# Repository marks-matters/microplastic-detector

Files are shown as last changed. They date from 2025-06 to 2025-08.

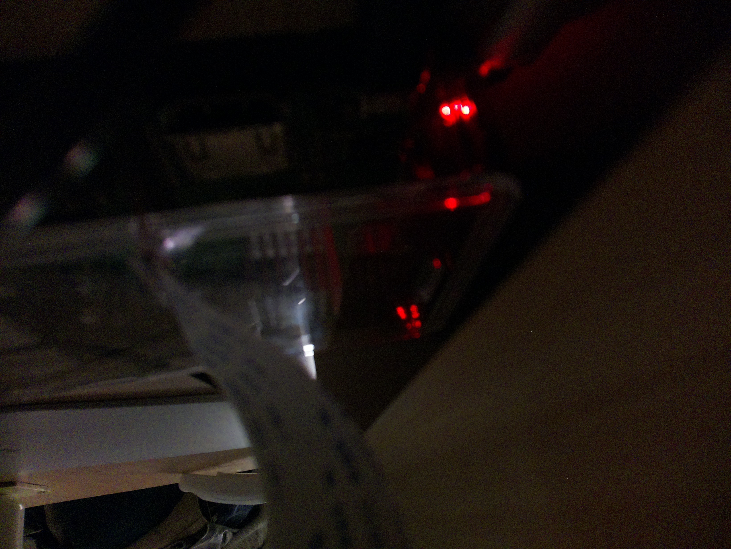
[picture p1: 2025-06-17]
tests/test-images/sample_20250616_235741.jpg

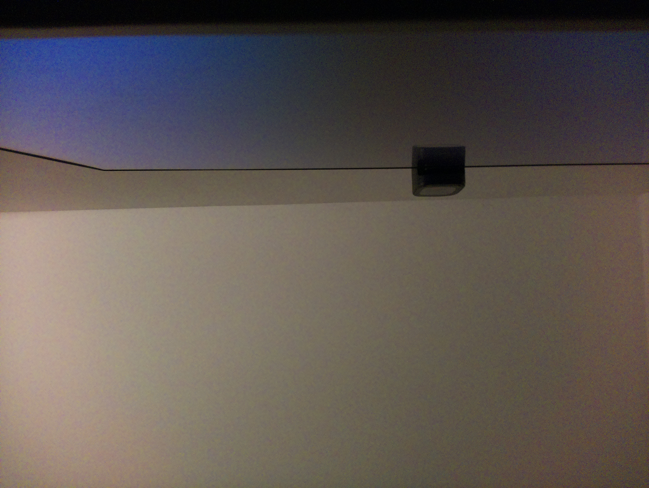
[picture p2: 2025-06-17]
tests/test-images/sample_20250616_233426.jpg

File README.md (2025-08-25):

# Microplastic Detector

A Python-based tool for analyzing fluorescence images to detect and categorize microplastic particles. This tool uses computer vision techniques to identify, count, and classify microplastic particles in fluorescence microscopy images.

## Features

- Automated detection of microplastic particles in fluorescence images
- Particle counting and size filtering
- Classification into Low/Medium/High concentration categories
- Visual output with multiple analysis stages
- Comprehensive test suite for reliability

## Prerequisites

- Python 3.13 or higher
- Virtual environment (included in repository)
- OpenCV
- NumPy
- Matplotlib
- pytest (for running tests)
- gpiozero

## Setup Instructions

1. Clone the repository:
   ```bash
   git clone <repository-url>
   cd microplastic-detector
   ```

2. Activate the virtual environment:
   ```bash
   source microplastics-env/bin/activate
   ```

3. Install required packages:
   ```bash
   pip install opencv-python numpy matplotlib pytest
   ```

### Setup Instructions for Raspberry Pi

0. Setup Raspberry Pi and install the camera:
   ```bash
   sudo ssh admin@microplastics-ui.local
   sudo raspi-config
   ```

   Go to:

   >   Interface Options → Camera → Enable

   Reboot:
   ```bash
   sudo reboot
   ```

1. Update `apt` and install dependencies `venv` and `opencv`:
   ```bash
   sudo apt update
   sudo apt install python3-venv python3-opencv -y
   ```

2. Set up project file and environment:
   ```bash
   cd ~
   mkdir mp-proj
   cd ~/mp-proj
   python3 -m venv --system-site-packages ~/mp-proj/mp-env
   python3 -m venv mp-env
   ```

3. Transfer files to the Raspberry Pi:
   ```bash
   sudo scp -r software admin@microplastics-ui.local:~/mp-proj/
   ```

4. Activate the virtual environment and install the required packages:
   ```bash
   cd ~/mp-proj
   source mp-env/bin/activate
   pip install -r software/requirements.txt
   ```

5. Run the python script
   ```bash
   python -m software.main
   ```

## Usage

To analyze a single image:

```bash
python -m software.analyze_microplastics --image_path image_name.jpg --show_image_processing
```

```python
from software.analyze_microplastics import analyze_microplastics

# Basic usage
count, category = analyze_microplastics("path/to/your/image.jpg")

# Advanced usage with all parameters
count, category = analyze_microplastics(
    image_path="path/to/your/image.jpg",
    min_area=10,                 # Minimum particle size in pixels
    max_area=5000,               # Maximum particle size in pixels
    low_thresh=10,               # Threshold for "Low" category
    high_thresh=30,              # Threshold for "Medium" category
    show_image_processing=False  # Whether to display visualization
)

print(f"Detected particles: {count}")
print(f"Concentration category: {category}")
```

### Parameters

- `image_path`: Path to the fluorescence image
- `min_area`: Minimum particle area to count (default: 10 pixels)
- `max_area`: Maximum particle area to count (default: 5000 pixels)
- `low_thresh`: Maximum particle count for "Low" classification (default: 10)
- `high_thresh`: Maximum particle count for "Medium" classification (default: 30)
- `show_image_processing`: Whether to display visualization plots (default: False)

### Return Values

Returns a tuple containing:
1. `count` (int): Number of detected particles
2. `category` (str): Concentration category ("Low", "Medium", or "High")

## Testing

The project includes comprehensive test suites for all components. To run the tests:

1. Ensure you're in the virtual environment:
   ```bash
   source microplastics-env/bin/activate
   ```

2. Run all tests:
   ```bash
   pytest tests/ -v
   ```

3. Run specific test files:
   ```bash
   pytest tests/test_analyze_microplastics.py -v  # Analysis tests
   pytest tests/test_capture_image.py -v          # Image capture tests
   pytest tests/test_main.py -v                   # Main pipeline tests
   ```

Additional test options:
- Use `-v` for verbose output
- Run specific tests: `pytest tests/test_capture_image.py -k "failure"`
- Show print statements: `pytest tests/ -s`

## Test Coverage

The test suite covers:

### Analysis Module
- Basic functionality and return types
- Threshold handling
- Area filtering
- Edge cases (zero/negative values)
- Input validation
- File handling
- Result consistency

### Image Capture Module
- Directory creation
- File naming conventions
- Error handling
- Hardware failure scenarios

### Main Pipeline
- Integration tests
- End-to-end workflow
- Error propagation

## Useful functions

To copy a file from the Raspberry Pi back to your local machine, use:

/home/admin/mp-proj/captures
```bash
sudo scp admin@microplastics-ui.local:/home/admin/mp-proj/captures/sample_20250801_225616.jpg ./captures/
```

## Contributing

1. Create a fork
2. Create your feature branch
3. Make your changes
4. Run the test suite to ensure everything works
5. Update documentation if needed (see Documentation section below)
6. Submit a pull request

## Documentation

This project includes automated documentation update triggers. When making changes to core functionality, please ensure documentation stays current:

### Files that may need updates:
- **README.md**: User-facing documentation, API examples, setup instructions
- **.github/instructions/microplastic-detector.instructions.md**: AI agent guidance and contracts
- **.cursor/rules/**: Documentation standards and automated update triggers

### Common update triggers:
- Function signature changes → Update README examples and AI contracts
- New dependencies → Update setup instructions
- New features → Document usage examples and workflows
- Directory structure changes → Update file listings and references
- Test structure changes → Update testing documentation

The repository includes automated rules in `.cursor/rules/` that will suggest documentation updates when relevant changes are detected. These rules include:

- **File organization standards**: Naming conventions and structure guidelines
- **Documentation triggers**: Broad change detection for documentation updates
- **README consistency**: Specific checks for README accuracy
- **AI instructions consistency**: Maintains AI guidance accuracy
- **Meta-update rules**: Self-referential updates for documentation standards

## License

This project is licensed under the MIT License - see the [LICENSE](LICENSE) file for details.

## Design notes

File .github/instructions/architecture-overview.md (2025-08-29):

---
description: High-level architecture and workflow overview for the microplastic detector
applyTo: "**"
---

# Architecture Overview

Purpose: Understand the big picture architecture and core workflow of the microplastic detector system.

## System Architecture

The microplastic detector consists of two main components:

### 1. Hardware-Enabled Python Pipeline (`software/`)
- **Purpose**: Complete capture → analysis → report workflow
- **Platform**: Raspberry Pi with camera and LED hardware
- **Components**:
  - Image capture using `libcamera-still`
  - LED illumination control via GPIO
  - OpenCV-based microplastic analysis
  - Result reporting and storage

### 2. Optional React Frontend (`app/`)
- **Purpose**: Standalone UI for visualization and interaction
- **Platform**: Web-based (Vite + React + TypeScript)
- **Status**: Not currently wired to Python backend
- **Use Case**: Development, demonstration, future web interface

## Core Workflow

The main pipeline (`software/main.py`) follows this sequence:

```
1. illuminate_sample(lights=True)     # Turn on LEDs (GPIO 23/24/27)
2. capture_image()                    # Run libcamera-still → captures/sample_YYYYMMDD_HHMMSS.jpg
3. analyze_microplastics(path)        # OpenCV HSV masks + morphology → count + risk level
4. finally: illuminate_sample(lights=False) + cleanup()  # Always turn off LEDs
```

### Analysis Pipeline Details

The `analyze_microplastics()` function implements:
1. **Color Space Conversion**: BGR → HSV
2. **Color Filtering**: Masks for deep_red, red, orange, yellow
3. **Image Processing**: Gaussian blur → bilateral filter → Otsu thresholding
4. **Morphological Operations**: Opening with 3×3 ellipse kernel
5. **Contour Detection**: Find and count particles
6. **Classification**: Count → Low/Medium/High risk categories

## Data Flow

```
Hardware Input → Image Capture → Analysis → Results
     ↓              ↓             ↓         ↓
LED + Camera → .jpg files → OpenCV → Count + Risk Level
```

## File Organization

- **`software/`**: Core Python modules
- **`captures/`**: Timestamped sample images
- **`tests/`**: Unit tests and test images
- **`app/`**: React frontend (standalone)
- **`hardware/`**: 3D models and hardware specs

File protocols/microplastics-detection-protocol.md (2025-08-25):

# Microplastics Detection Protocol

## Materials
- **Tap water sample**, 20 mL
- **Syringe**, ≤10 mL capacity
- **Pipette**, ≥10 mL capacity
- **Filter holder** with funnel and vacuum-enabled catchment beaker
- **Nylon membrane filter**, 47 mm diameter, 0.22 µm pore size
- **Vacuum pump**, 5v
- **Absolute ethanol**, ≥96%
- **Nile Red powder**
- **2 x amber vials** for stock and working solutions
- **Micropipette** for 100 µL dispensing
- **Raspberry Pi Camera 2** with lense manually turned to desired focal distance
- **6 mm macro lens**
- **LEE Lee No. 105 Orange (~560 nm) long-pass emission filter**
- **LED ring with camera window and leg threads**, the 10 x LED slots angled inwards at 45° and 5 x leg threads
- **10 x green LED lights** with a wavelength of 485–545 nm (peak at 515 nm) and a viewing angle of 50°
- **5 x 60 mm legs** with screw thread
- **Light shield** to block out light during florencence and imaging
- **N-MOSFET**, logic-level
- **Resistors**, 11 x 220 Ω (one per LED and one for the MOSFET gate) and 1 x 10 kΩ as a gate pull-down
- **5 V regulated supply** via Raspberry Pi 5 V rail
- **Petri dishes**, 60 mm, for positioning membrane, and 50 mm for covering during staining
- **Raspberry Pi** with image capture and analysis software
- **Breadboard** for wiring up LEDs, MOSFET and vacuum
- **Connector cables**

---

## 1. Nile Red Working Solution Preparation
- **Stock solution**: 1 mg/mL Nile Red in absolute ethanol (96%).  
- **Working solution**: dilute 0.1 mL stock + 0.9 mL ethanol to get **100 µg/mL**.  
- Prepare working solution fresh before staining.

---

## 2. Sample Measurement
- Measure **20 mL** of tap water using a clean syringe or pipette.  
- No pretreatment (e.g., oxidation or digestion) is applied.

---

## 3. Filtration
- Place a **47 mm nylon membrane filter, with 0.22 µm pore size** into the filter holder.  
- Pass the **20 mL sample** through the membrane using **gentle vacuum**.  
- Allow the membrane to **partially air dry** under gentle vacuum.

---

## 4. Staining the Membrane
- Transfer the membrane to a **60 mm Petri dish**.
- **Apply 4-5 drops**, totalling ~100 µL, of the 100 µg/mL Nile Red working solution evenly over the surface.
- Incubate for **30 minutes**, partially covered with another Petri dish and protected from light.
<!-- - Apply gentle vacuum for **1 minute** to remove excess solution. -->

---

## 5. Imaging Setup
- Use a **Raspberry Pi Camera 2** with an attached **6 mm lens** at **60 mm distance** from the membrane.
- **Emission filter** (Orange) placed behind the lens.
- **10 green LEDs** (515 nm) mounted in parallel, with 220 Ω resistors, at ~45° around membrane.
- LEDs powered from 5 V rail, switched by N-MOSFET from Pi GPIO.
- LEDs on during capture; camera uses long exposure.

---

## 6. Image Capture & Processing
- Capture image via Pi software.
- Processing pipeline:
  1. Convert to HSV color space.
  2. Mask relevant hue ranges (deep red/red/orange).
  3. Blur, threshold, and clean image.
  4. Detect contours and count particles.
  5. Classify count into **Low / Medium / High**.

---

## 7. Cleanup
- Turn off LEDs via software.
- Remove or store membrane as needed.
- Save image and analysis output.

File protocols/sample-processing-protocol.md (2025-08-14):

# Microplastics Detection Protocol

## 1. Sample Measurement
- Measure **10 mL** of tap water using a clean syringe or pipette.  
- No pretreatment (e.g., oxidation or digestion) is applied.

---

## 2. Filtration
- Place a **47 mm nylon membrane filter** (0.22 µm pore size) into the filter holder.  
- Pass the **10 mL sample** through the membrane using gentle vacuum.  
- Allow the membrane to **air dry under gentle vacuum** until mostly dry.

---

## 3. Nile Red Working Solution Preparation
- **Stock solution**: 1 mg/mL Nile Red in absolute ethanol (96%).  
- **Working solution**: dilute 0.1 mL stock + 0.9 mL ethanol to get **100 µg/mL**.  
- Prepare working solution fresh before staining.

---

## 4. Staining the Membrane
- With the membrane still in the holder:
  - Apply ~100 µL of the **100 µg/mL Nile Red** working solution evenly over the surface.
  - Incubate for **2 minutes** protected from light.
  - Apply gentle vacuum for **1 minute** to remove excess solution.

---

## 5. Imaging Setup
- Keep membrane in place on holder or 60 mm Petri dish.
- Use **Raspberry Pi Camera 2** + **6 mm lens** at **60 mm distance** from membrane.
- **Emission filter** (golden amber) placed behind the lens.
- **10 green LEDs** (560–568 nm) mounted at ~45° around membrane.
- LEDs powered from 5 V rail, switched by N-MOSFET from Pi GPIO.
- LEDs on during capture; camera uses long exposure.

---

## 6. Image Capture & Processing
- Capture image via Pi software.
- Processing pipeline:
  1. Convert to HSV color space.
  2. Mask relevant hue ranges (red/orange/yellow/green).
  3. Blur, threshold, and clean image.
  4. Detect contours and count particles.
  5. Classify count into **Low / Medium / High**.

---

## 7. Cleanup
- Turn off LEDs via software.
- Remove or store membrane as needed.
- Save image and analysis output.

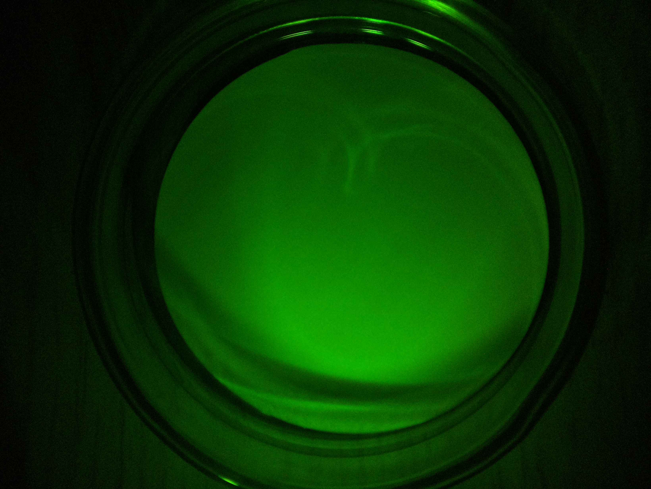
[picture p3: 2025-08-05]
captures/sample_20250801_225616.jpg

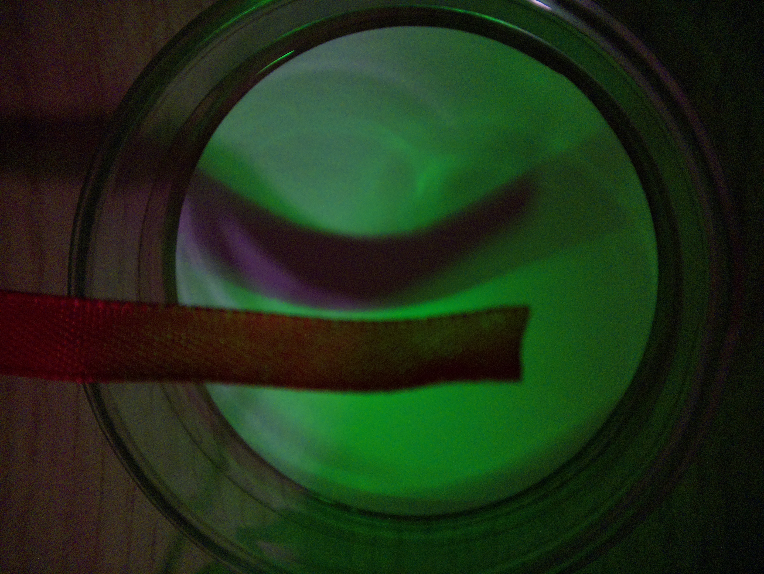
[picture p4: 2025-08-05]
captures/sample_20250801_232240.jpg

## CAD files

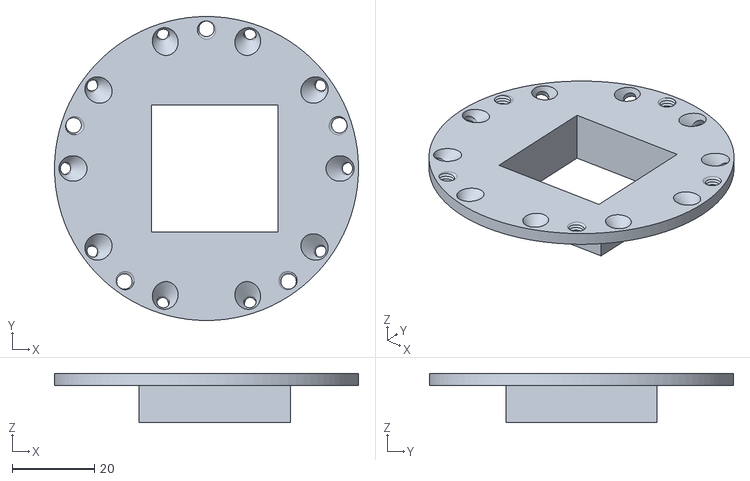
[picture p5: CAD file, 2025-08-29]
hardware/core_body_WP710A10ZGDK_10.stl
74.0 x 74.0 x 12.0

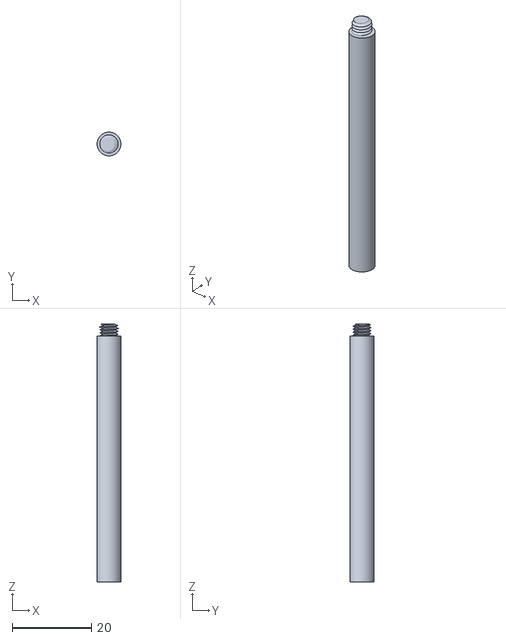
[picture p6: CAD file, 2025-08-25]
hardware/core_leg_62.stl
6.00 x 6.00 x 65.0

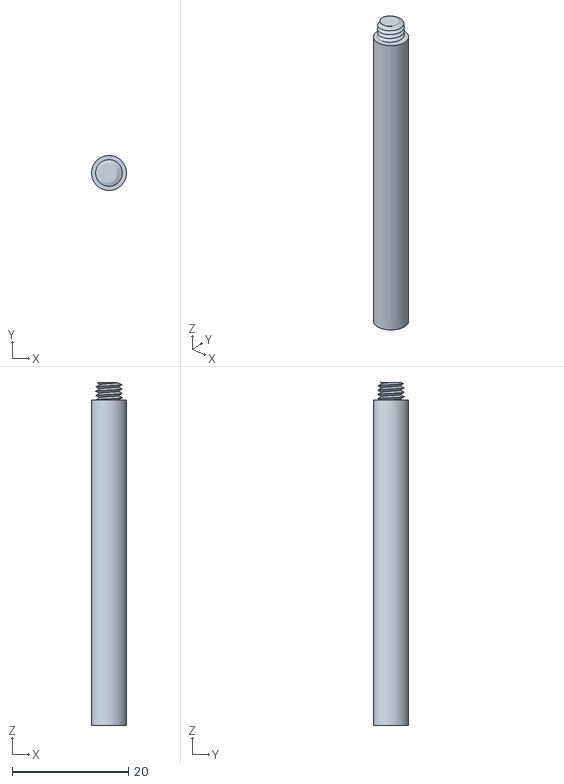
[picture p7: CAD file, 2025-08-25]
hardware/core_leg_56.stl
6.00 x 6.00 x 59.0

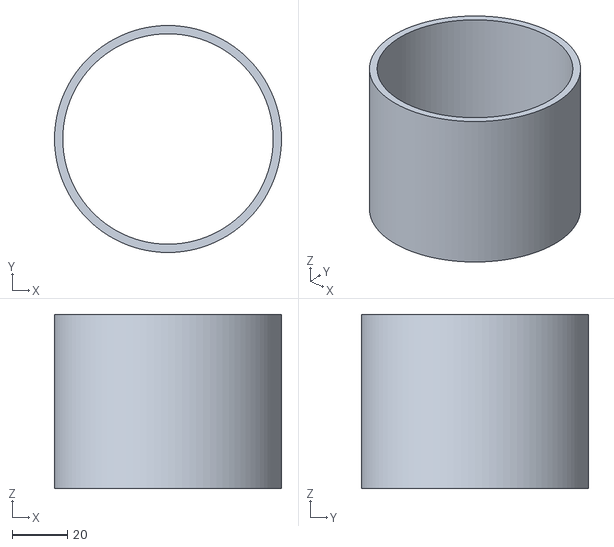
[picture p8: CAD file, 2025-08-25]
hardware/core_cover_v2.stl
82.0 x 82.0 x 63.0

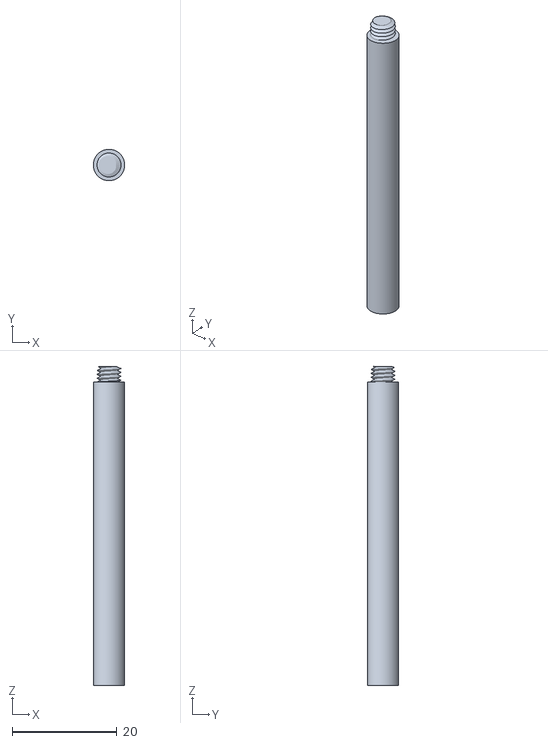
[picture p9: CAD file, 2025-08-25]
hardware/core_leg_58.stl
6.00 x 6.00 x 61.0

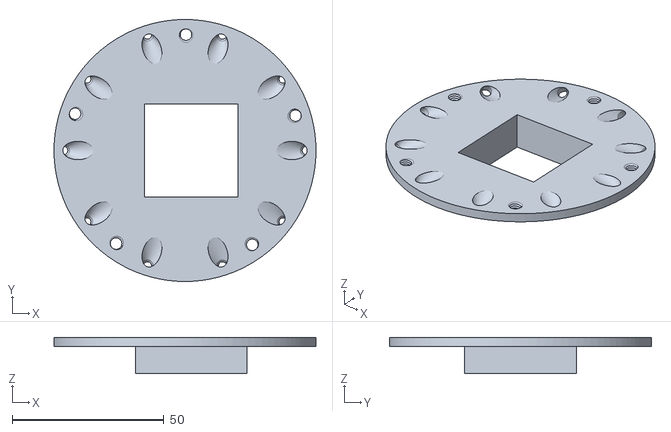
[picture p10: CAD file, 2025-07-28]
hardware/core_body.stl
86.4 x 86.4 x 12.0

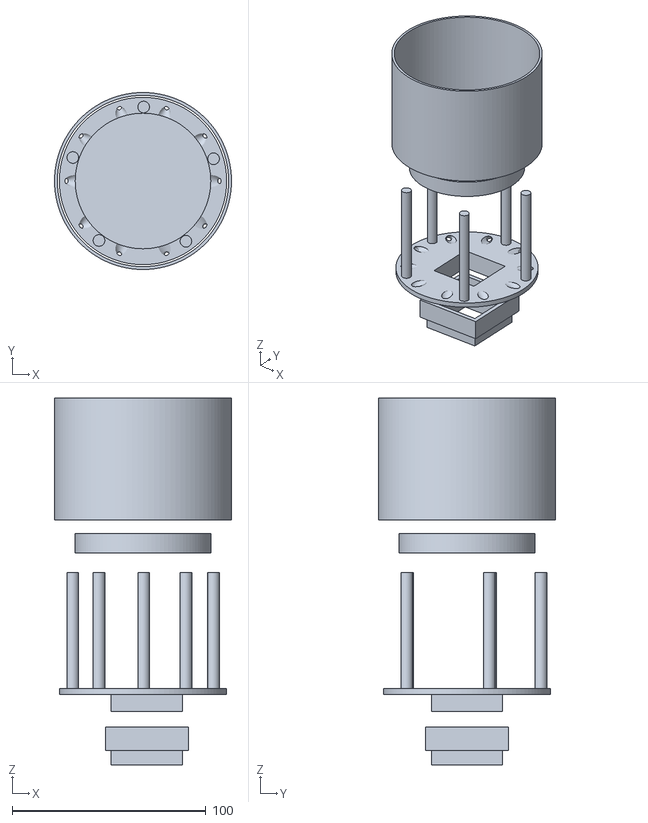
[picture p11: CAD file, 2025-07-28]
hardware/md_housing_v0.stl
91.4 x 91.4 x 189.5

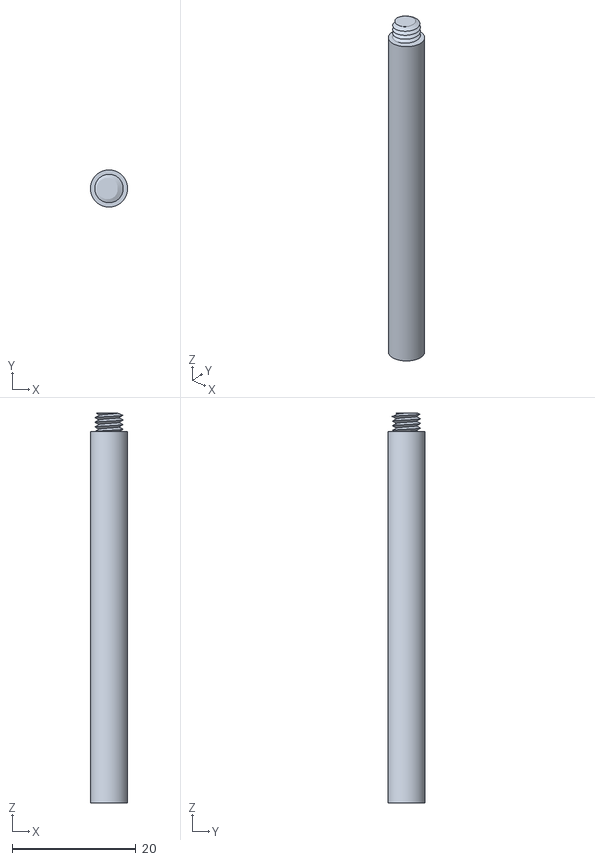
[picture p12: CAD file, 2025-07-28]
hardware/core_leg.stl
6.00 x 6.00 x 63.0

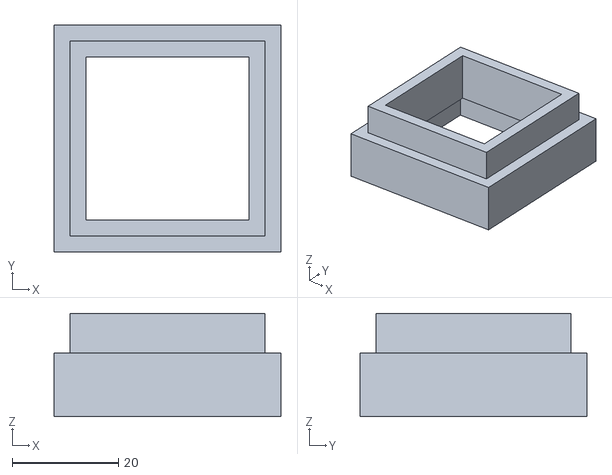
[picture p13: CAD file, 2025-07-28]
hardware/camera_extension.stl
42.8 x 42.8 x 19.5

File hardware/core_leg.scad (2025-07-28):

// Created 2016-2017 by Ryan A. Colyer.
// This work is released with CC0 into the public domain.
// https://creativecommons.org/publicdomain/zero/1.0/
//
// https://www.thingiverse.com/thing:1686322
//
// v2.1

$fn = 100;

screw_resolution = 0.5;  // in mm

// Legs
leg_diameter = 6;
leg_height = 60;

// Provides standard metric thread pitches.
function ThreadPitch(diameter) =
  (diameter <= 64) ?
    lookup(diameter, [
      [2, 0.4],
      [2.5, 0.45],
      [3, 0.5],
      [4, 0.7],
      [5, 0.8],
      [6, 1.0],
      [7, 1.0],
      [8, 1.25],
      [10, 1.5],
      [12, 1.75],
      [14, 2.0],
      [16, 2.0],
      [18, 2.5],
      [20, 2.5],
      [22, 2.5],
      [24, 3.0],
      [27, 3.0],
      [30, 3.5],
      [33, 3.5],
      [36, 4.0],
      [39, 4.0],
      [42, 4.5],
      [48, 5.0],
      [52, 5.0],
      [56, 5.5],
      [60, 5.5],
      [64, 6.0]
    ]) :
    diameter * 6.0 / 64;


// This generates a closed polyhedron from an array of arrays of points,
// with each inner array tracing out one loop outlining the polyhedron.
// pointarrays should contain an array of N arrays each of size P outlining a
// closed manifold.  The points must obey the right-hand rule.  For example,
// looking down, the P points in the inner arrays are counter-clockwise in a
// loop, while the N point arrays increase in height.  Points in each inner
// array do not need to be equal height, but they usually should not meet or
// cross the line segments from the adjacent points in the other arrays.
// (N>=2, P>=3)
// Core triangles:
//   [j][i], [j+1][i], [j+1][(i+1)%P]
//   [j][i], [j+1][(i+1)%P], [j][(i+1)%P]
//   Then triangles are formed in a loop with the middle point of the first
//   and last array.
module ClosePoints(pointarrays) {
  function recurse_avg(arr, n=0, p=[0,0,0]) = (n>=len(arr)) ? p :
    recurse_avg(arr, n+1, p+(arr[n]-p)/(n+1));

  N = len(pointarrays);
  P = len(pointarrays[0]);
  NP = N*P;
  lastarr = pointarrays[N-1];
  midbot = recurse_avg(pointarrays[0]);
  midtop = recurse_avg(pointarrays[N-1]);

  faces_bot = [
    for (i=[0:P-1])
      [0,i+1,1+(i+1)%len(pointarrays[0])]
  ];

  loop_offset = 1;
  bot_len = loop_offset + P;

  faces_loop = [
    for (j=[0:N-2], i=[0:P-1], t=[0:1])
      [loop_offset, loop_offset, loop_offset] + (t==0 ?
      [j*P+i, (j+1)*P+i, (j+1)*P+(i+1)%P] :
      [j*P+i, (j+1)*P+(i+1)%P, j*P+(i+1)%P])
  ];

  top_offset = loop_offset + NP - P;
  midtop_offset = top_offset + P;

  faces_top = [
    for (i=[0:P-1])
      [midtop_offset,top_offset+(i+1)%P,top_offset+i]
  ];

  points = [
    for (i=[-1:NP])
      (i<0) ? midbot :
      ((i==NP) ? midtop :
      pointarrays[floor(i/P)][i%P])
  ];
  faces = concat(faces_bot, faces_loop, faces_top);

  polyhedron(points=points, faces=faces);
}

// This creates a vertical rod at the origin with external threads.  It uses
// metric standards by default.
module ScrewThread(outer_diam, height, pitch=0, tooth_angle=30, tolerance=0.4, tip_height=0, tooth_height=0, tip_min_fract=0) {

  pitch = (pitch==0) ? ThreadPitch(outer_diam) : pitch;
  tooth_height = (tooth_height==0) ? pitch : tooth_height;
  tip_min_fract = (tip_min_fract<0) ? 0 :
    ((tip_min_fract>0.9999) ? 0.9999 : tip_min_fract);

  outer_diam_cor = outer_diam + 0.25*tolerance; // Plastic shrinkage correction
  inner_diam = outer_diam - tooth_height/tan(tooth_angle);
  or = (outer_diam_cor < screw_resolution) ?
    screw_resolution/2 : outer_diam_cor / 2;
  ir = (inner_diam < screw_resolution) ? screw_resolution/2 : inner_diam / 2;
  height = (height < screw_resolution) ? screw_resolution : height;

  steps_per_loop_try = ceil(2*3.14159265359*or / screw_resolution);
  steps_per_loop = (steps_per_loop_try < 4) ? 4 : steps_per_loop_try;
  hs_ext = 3;
  hsteps = ceil(3 * height / pitch) + 2*hs_ext;

  extent = or - ir;

  tip_start = height-tip_height;
  tip_height_sc = tip_height / (1-tip_min_fract);

  tip_height_ir = (tip_height_sc > tooth_height/2) ?
    tip_height_sc - tooth_height/2 : tip_height_sc;

  tip_height_w = (tip_height_sc > tooth_height) ? tooth_height : tip_height_sc;
  tip_wstart = height + tip_height_sc - tip_height - tip_height_w;


  function tooth_width(a, h, pitch, tooth_height, extent) =
    let(
      ang_full = h*360.0/pitch-a,
      ang_pn = atan2(sin(ang_full), cos(ang_full)),
      ang = ang_pn < 0 ? ang_pn+360 : ang_pn,
      frac = ang/360,
      tfrac_half = tooth_height / (2*pitch),
      tfrac_cut = 2*tfrac_half
    )
    (frac > tfrac_cut) ? 0 : (
      (frac <= tfrac_half) ?
        ((frac / tfrac_half) * extent) :
        ((1 - (frac - tfrac_half)/tfrac_half) * extent)
    );


  pointarrays = [
    for (hs=[0:hsteps])
      [
        for (s=[0:steps_per_loop-1])
          let(
            ang_full = s*360.0/steps_per_loop,
            ang_pn = atan2(sin(ang_full), cos(ang_full)),
            ang = ang_pn < 0 ? ang_pn+360 : ang_pn,

            h_fudge = pitch*0.001,

            h_mod =
              (hs%3 == 2) ?
                ((s == steps_per_loop-1) ? tooth_height - h_fudge : (
                 (s == steps_per_loop-2) ? tooth_height/2 : 0)) : (
              (hs%3 == 0) ?
                ((s == steps_per_loop-1) ? pitch-tooth_height/2 : (
                 (s == steps_per_loop-2) ? pitch-tooth_height + h_fudge : 0)) :
                ((s == steps_per_loop-1) ? pitch-tooth_height/2 + h_fudge : (
                 (s == steps_per_loop-2) ? tooth_height/2 : 0))
              ),

            h_level =
              (hs%3 == 2) ? tooth_height - h_fudge : (
              (hs%3 == 0) ? 0 : tooth_height/2),

            h_ub = floor((hs-hs_ext)/3) * pitch
              + h_level + ang*pitch/360.0 - h_mod,
            h_max = height - (hsteps-hs) * h_fudge,
            h_min = hs * h_fudge,
            h = (h_ub < h_min) ? h_min : ((h_ub > h_max) ? h_max : h_ub),

            ht = h - tip_start,
            hf_ir = ht/tip_height_ir,
            ht_w = h - tip_wstart,
            hf_w_t = ht_w/tip_height_w,
            hf_w = (hf_w_t < 0) ? 0 : ((hf_w_t > 1) ? 1 : hf_w_t),

            ext_tip = (h <= tip_wstart) ? extent : (1-hf_w) * extent,
            wnormal = tooth_width(ang, h, pitch, tooth_height, ext_tip),
            w = (h <= tip_wstart) ? wnormal :
              (1-hf_w) * wnormal +
              hf_w * (0.1*screw_resolution + (wnormal * wnormal * wnormal /
                (ext_tip*ext_tip+0.1*screw_resolution))),
            r = (ht <= 0) ? ir + w :
              ( (ht < tip_height_ir ? ((2/(1+(hf_ir*hf_ir))-1) * ir) : 0) + w)
          )
          [r*cos(ang), r*sin(ang), h]
      ]
  ];


  ClosePoints(pointarrays);
}

// Solid rod on the bottom, external threads on the top.
module RodStart(height, diameter, thread_len=0, thread_diam=0, thread_pitch=0) {
  // A reasonable default.
  thread_diam = (thread_diam==0) ? 0.75*diameter : thread_diam;
  thread_len = (thread_len==0) ? 0.5*diameter : thread_len;
  thread_pitch = (thread_pitch==0) ? ThreadPitch(thread_diam) : thread_pitch;

  cylinder(r=diameter/2, h=height, $fn=24*diameter);

  translate([0, 0, height])
    ScrewThread(thread_diam, thread_len, thread_pitch,
      tip_height=thread_pitch, tip_min_fract=0.75);
}

// Legs
module leg() {
  RodStart(leg_height, leg_diameter);
}

// Render
leg();

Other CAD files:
hardware/core_body_WP710A10ZGDK.stl
hardware/core_leg_100.scad
hardware/core_leg_56.scad
hardware/core_leg_58.scad
hardware/camera_extension.scad
hardware/core_body.scad
hardware/core_body_151031VS06000.scad
hardware/core_body_WP710A10ZGDK.scad
hardware/core_cover.scad
hardware/core_cover_v2.scad
hardware/core_leg_62.scad
hardware/core_leg_64.scad
hardware/core_leg_66.scad
hardware/core_leg_70.scad
hardware/core_leg_80.scad
hardware/core_leg_90.scad
hardware/full housing.scad
hardware/led angels and dispersion of light onto membrane.scad

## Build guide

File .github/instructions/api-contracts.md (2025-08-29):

---
description: Critical API contracts and function signatures that must not be broken
applyTo: "**"
---

# API Contracts

Purpose: Document critical function signatures and behaviors that must be preserved to maintain system integrity.

## ⚠️ DO NOT BREAK THESE CONTRACTS

### `software/analyze_microplastics.py`

**Function Signature:**
```python
analyze_microplastics(image_path, min_area=10, max_area=5000, low_thresh=10, high_thresh=30, show_image_processing=False) -> (int, str)
```

**Input Validations:**
- `min_area <= max_area` else raise `ValueError`
- Clamp negative values to ≥ 0
- Enforce `high_thresh >= low_thresh`

**Error Handling:**
- Missing file → `FileNotFoundError`
- Unreadable image → `ValueError`

**Processing Pipeline (Fixed Order):**
1. BGR → HSV color space conversion
2. Color masks for: `deep_red`, `red`, `orange`, `yellow`
3. Gaussian blur (3×3 kernel)
4. Bilateral filter
5. Otsu thresholding
6. Morphological opening (3×3 ellipse kernel)
7. Contour detection

**Counting Rules:**
- Include contours where: `min_area < contour_area < max_area`

**Classification Rules:**
- `count < low_thresh` → `"Low"`
- `count < high_thresh` → `"Medium"`
- `count >= high_thresh` → `"High"`

**Visualization:**
- Show processing steps only when `show_image_processing=True`
- Tests must set matplotlib backend to `'Agg'`

### `software/capture_image.py`

**Core Behavior:**
- Build `libcamera-still` command with optional camera controls
- Support parameters: shutter, gain, iso, metering, roi, awb, awbgains
- Ensure output directory exists
- Return absolute path to captured image
- Raise `RuntimeError` on nonzero exit code

**File Naming Contract:**
- Must use pattern: `captures/sample_*.jpg`
- Timestamp format: `YYYYMMDD_HHMMSS`

### `software/illuminate_sample.py`

**Hardware Interface:**
- Use `gpiozero.LED` for GPIO pins: 23, 24, 27
- `cleanup()` function must close all LED objects
- LED objects created on module import

**Error Handling:**
- Must handle GPIO cleanup gracefully
- Ensure LEDs are turned off on exit

### `software/main.py`

**Critical Requirement:**
- `run_capture_and_analysis()` must ALWAYS turn off LEDs in `finally` block
- LED cleanup must occur even if analysis fails
- No exceptions should prevent LED cleanup

## Return Value Contracts

### `analyze_microplastics()`
```python
return (particle_count: int, risk_level: str)
# where risk_level in ["Low", "Medium", "High"]
```

### `capture_image()`
```python
return image_path: str
# Absolute path to captured image file
```

## Testing Contracts

- Mock `subprocess.run` in capture tests
- `test_main` must patch both `capture_image` and `analyze_microplastics`
- Preserve default parameter values in tests
- HSV color ranges are part of the contract and covered by tests

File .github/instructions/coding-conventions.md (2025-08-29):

---
description: Coding conventions, patterns, and organizational standards
applyTo: "**"
---

# Coding Conventions

Purpose: Maintain consistent code style and organizational patterns throughout the project.

## File Organization

### Output Files
- Keep all capture outputs under `captures/` directory
- Use `sample_` prefix with timestamp: `sample_YYYYMMDD_HHMMSS.jpg`
- Ensure timestamp format consistency across modules

### Module Structure
- Core functionality in `software/` package
- Keep modules focused and single-purpose
- Use clear, descriptive module names

## Code Patterns

### Side Effects
- **Avoid side effects** outside of `run_capture_and_analysis()`
- Functions should be pure when possible
- Minimize global state modifications

### Visualization
- **Avoid showing plots by default** in analysis functions
- Use explicit `show_image_processing` parameter for visualization
- Set matplotlib backend appropriately for testing environment

### Error Handling
- Always ensure LED cleanup in error paths
- Use appropriate exception types (`FileNotFoundError`, `ValueError`, `RuntimeError`)
- Provide meaningful error messages

## Configuration Management

### Default Parameters
- **Preserve threshold defaults** - they are part of the tested contract
- HSV color ranges are validated by tests - don't modify arbitrarily
- Area thresholds (`min_area=10`, `max_area=5000`) are empirically determined

### Hardware Configuration
- GPIO pin assignments (23, 24, 27) are fixed in hardware design
- Camera parameters should remain configurable through function arguments
- LED cleanup must be robust and always executed

## Import Patterns

### Module Imports
```python
# Prefer absolute imports within package
from software.analyze_microplastics import analyze_microplastics
from software.capture_image import capture_image
from software.illuminate_sample import illuminate_sample, cleanup
```

### External Dependencies
- Use `gpiozero` for GPIO control (Raspberry Pi)
- Prefer `opencv-python` for development, `python3-opencv` for Pi
- Import hardware-specific modules conditionally when possible

## Testing Patterns

### Mocking
- Mock `subprocess.run` for camera operations in tests
- Patch hardware-dependent functions in integration tests
- Use `@patch` decorators consistently

### Test Data
- Store test images in `tests/test-images/`
- Use descriptive test image names
- Include variety of particle counts and types

### Assertions
- Test both positive and negative cases
- Validate error conditions and edge cases
- Check return value types and formats

## Documentation Patterns

### Function Documentation
- Document parameter validation rules
- Specify return value formats
- Note side effects (LED control, file creation)
- Include usage examples for complex functions

### Code Comments
- Explain algorithm steps in analysis pipeline
- Document hardware-specific requirements
- Note contract requirements and constraints

## Performance Considerations

### Image Processing
- Use efficient OpenCV operations
- Minimize memory allocations in loops
- Consider image size impacts on processing time

### File I/O
- Ensure directory existence before file operations
- Use absolute paths to avoid confusion
- Clean up temporary files when appropriate

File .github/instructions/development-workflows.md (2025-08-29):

---
description: Development commands, testing procedures, and workflow guidance
applyTo: "**"
---

# Development Workflows

Purpose: Standard commands and procedures for developing and testing the microplastic detector.

## Local Development

### Analyzer-Only Testing
Run the analysis module on test images without hardware:

```bash
python -m software.analyze_microplastics --image_path tests/test-images/test_image_1.jpg
```

This is useful for:
- Algorithm development
- Testing on non-Raspberry Pi systems
- Validating analysis parameters

### Full Pipeline (Raspberry Pi)
Run the complete capture and analysis workflow:

```bash
python -m software.main
```

Requirements:
- Raspberry Pi with camera module
- LEDs wired to GPIO pins 23, 24, 27
- `libcamera-still` available

## Testing

### Run All Tests
```bash
pytest tests/ -v
```

### Run Specific Test Modules
```bash
# Test analysis module
pytest tests/test_analyze_microplastics.py -v

# Test image capture
pytest tests/test_capture_image.py -v

# Test main workflow
pytest tests/test_main.py -v
```

### Test Environment Notes
- Tests mock `subprocess.run` for capture functionality
- `test_main` patches both `capture_image` and `analyze_microplastics`
- Matplotlib backend set to `'Agg'` for headless testing
- Test images available in `tests/test-images/`

## Frontend Development

### React App (`app/`)
```bash
# Navigate to app directory
cd app/

# Install dependencies
npm install

# Development server
npm run dev

# Build for production
npm run build

# Preview production build
npm run preview
```

**Note**: Frontend is currently standalone and not connected to Python backend.

## Environment Setup

### Python Environment
```bash
# Create virtual environment
python -m venv microplastics-env

# Activate (macOS/Linux)
source microplastics-env/bin/activate

# Activate (Windows)
microplastics-env\Scripts\activate

# Install dependencies
pip install -r software/requirements.txt
```

### Platform-Specific Dependencies
- **Raspberry Pi**: `apt install python3-opencv libcamera-tools`
- **Development**: `pip install opencv-python pytest`

## Debug Workflows

### Capture Issues
1. Check camera connection: `libcamera-hello`
2. Test manual capture: `libcamera-still -o test.jpg`
3. Verify GPIO wiring for LEDs

### Analysis Issues
1. Use `show_image_processing=True` to visualize pipeline
2. Check HSV color ranges with test images
3. Adjust area thresholds for different particle sizes

### Integration Issues
1. Verify file paths in `captures/` directory
2. Check LED cleanup in error conditions
3. Monitor GPIO state during debugging

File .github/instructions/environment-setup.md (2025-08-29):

---
description: Platform-specific setup, dependencies, and environment configuration
applyTo: "**"
---

# Environment Setup

Purpose: Guide setup and dependency management across different development and deployment environments.

## Platform Requirements

### Raspberry Pi (Production)
**Operating System:** Raspberry Pi OS (recommended)

**Hardware Dependencies:**
- Camera module (compatible with `libcamera`)
- LEDs wired to GPIO pins 23, 24, 27
- Appropriate resistors for LED current limiting

**System Packages:**
```bash
# Update system
sudo apt update && sudo apt upgrade

# Install camera tools
sudo apt install libcamera-tools

# Install OpenCV (prefer system package)
sudo apt install python3-opencv

# Install Python development tools
sudo apt install python3-pip python3-venv
```

**Camera Configuration:**
- Enable camera interface: `sudo raspi-config` → Interface Options → Camera
- Test camera: `libcamera-hello` (should show preview)
- Test capture: `libcamera-still -o test.jpg`

### Development Environment (macOS/Linux/Windows)

**Python Requirements:**
- Python 3.8+ recommended
- Virtual environment setup strongly recommended

**Installation:**
```bash
# Create and activate virtual environment
python -m venv microplastics-env
source microplastics-env/bin/activate  # macOS/Linux
# microplastics-env\Scripts\activate  # Windows

# Install dependencies
pip install -r software/requirements.txt
```

**Development-Only Packages:**
```bash
# Install OpenCV for development
pip install opencv-python

# Install testing tools
pip install pytest pytest-cov

# Install development tools
# pip install black flake8 mypy
```

## Dependency Management

### Core Dependencies (`software/requirements.txt`)
- `opencv-python` or system `python3-opencv`
- `gpiozero` (Raspberry Pi GPIO control)
- `numpy` (included with OpenCV)
- `matplotlib` (visualization, optional)

### Platform-Specific Handling

**Raspberry Pi:**
```python
# GPIO operations work normally
from gpiozero import LED
led = LED(23)
```

**Development Systems:**
```python
# Mock GPIO when not on Pi
try:
    from gpiozero import LED
except ImportError:
    # Provide mock or skip GPIO operations
    pass
```

### Camera Dependencies

**Raspberry Pi:**
- `libcamera-still` must be available in PATH
- Camera module must be enabled in `raspi-config`

**Development Systems:**
- Mock `subprocess.run` calls to `libcamera-still`
- Use existing test images for analysis development

## Environment Variables

### Optional Configuration
```bash
# Set custom capture directory
export MICROPLASTIC_CAPTURES_DIR="/custom/path/captures"

# Configure analysis parameters
export MICROPLASTIC_MIN_AREA="15"
export MICROPLASTIC_MAX_AREA="4000"
```

## Troubleshooting

### Common Raspberry Pi Issues

**Camera Not Detected:**
```bash
# Check camera connection
libcamera-hello

# Verify camera interface enabled
sudo raspi-config

# Check for hardware errors
dmesg | grep -i camera
```

**GPIO Permission Issues:**
```bash
# Add user to gpio group
sudo usermod -a -G gpio $USER

# Restart session or reboot
sudo reboot
```

**OpenCV Import Errors:**
```bash
# Remove pip opencv if system opencv installed
pip uninstall opencv-python

# Install system opencv
sudo apt install python3-opencv
```

### Development Environment Issues

**Virtual Environment:**
```bash
# Ensure virtual environment is activated
which python  # Should point to venv

# Reinstall requirements if needed
pip install -r software/requirements.txt --force-reinstall
```

**Import Errors:**
```bash
# Run from project root
cd /path/to/microplastic-detector
python -m software.analyze_microplastics --help
```

## Performance Optimization

### Raspberry Pi
- Use system OpenCV package (faster than pip version)
- Enable camera hardware acceleration if available
- Monitor memory usage during analysis

### Development
- Use smaller test images for faster iteration
- Enable matplotlib caching for repeated visualizations
- Consider image downsampling for algorithm development

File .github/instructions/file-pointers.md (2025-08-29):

---
description: Quick reference to key files and directories in the project
applyTo: "**"
---

# File Pointers

Purpose: Quick reference guide to important files and directories for efficient navigation.

## Core Python Modules

### Main Pipeline
- **`software/main.py`**: Entry point for complete capture and analysis workflow
- **`software/analyze_microplastics.py`**: Core analysis algorithm with OpenCV processing
- **`software/capture_image.py`**: Camera control and image capture functionality
- **`software/illuminate_sample.py`**: LED control for sample illumination

### Supporting Files
- **`software/__init__.py`**: Package initialization
- **`software/requirements.txt`**: Python dependencies

## Testing Infrastructure

### Test Modules
- **`tests/test_analyze_microplastics.py`**: Analysis algorithm tests
- **`tests/test_capture_image.py`**: Image capture tests
- **`tests/test_main.py`**: Integration tests for main workflow

### Test Data
- **`tests/test-images/`**: Sample images for testing analysis
  - `test_image_1.jpg` through `test_image_7.jpg`
  - Real sample images from various dates

## Data and Output

### Image Storage
- **`captures/`**: Runtime image capture directory
  - Naming pattern: `sample_YYYYMMDD_HHMMSS.jpg`
  - Automatically created by capture module

### Configuration
- **`microplastics-env/`**: Python virtual environment
- **`__pycache__/`**: Python bytecode cache (auto-generated)

## Frontend Application

### Core Files
- **`app/src/App.tsx`**: Main React component
- **`app/src/main.tsx`**: Application entry point
- **`app/package.json`**: Node.js dependencies and scripts
- **`app/vite.config.ts`**: Vite build configuration

### Configuration
- **`app/tailwind.config.js`**: Tailwind CSS configuration
- **`app/postcss.config.mjs`**: PostCSS configuration
- **`app/styles.css`**: Global stylesheets

### Components
- **`app/src/components/`**: React component library

## Documentation

### User Documentation
- **`README.md`**: Main project documentation
- **`protocols/microplastics-detection-protocol.md`**: Scientific methodology

### AI Instructions
- **`.github/instructions/`**: Modular AI guidance files
  - `architecture-overview.md`
  - `api-contracts.md`
  - `development-workflows.md`
  - `coding-conventions.md`
  - `environment-setup.md`
  - `frontend-guidelines.md`
  - `documentation-sync.md`

### Automation Rules
- **`.cursor/rules/`**: Documentation maintenance automation
  - `README.md`: Rules overview
  - Various `.mdc` files for specific triggers

## Hardware and Design

### 3D Models
- **`hardware/`**: CAD files and STL models
  - `core_body.scad/.stl`: Main housing components
  - `core_cover_v2.scad/.stl`: Cover designs
  - `core_leg_*.scad/.stl`: Support legs (various sizes)
  - `camera_extension.scad/.stl`: Camera mounting

### Assembly
- **`hardware/full housing.scad`**: Complete assembly model
- **`hardware/led angels and dispersion of light onto membrane.scad`**: Lighting analysis

## Project Configuration

### Version Control
- **`.git/`**: Git repository data
- **`LICENSE`**: Project license information

### Development Environment
- **`.cursor/`**: Cursor IDE configuration and rules
- **`.github/`**: GitHub-specific configurations and instructions

## Quick Access Patterns

### For Algorithm Development
```
software/analyze_microplastics.py    # Main algorithm
tests/test_analyze_microplastics.py  # Algorithm tests
tests/test-images/                   # Test data
```

### For Hardware Integration
```
software/main.py                     # Integration point
software/capture_image.py            # Camera interface
software/illuminate_sample.py        # LED control
```

### For Frontend Development
```
app/src/                            # React source code
app/package.json                    # Dependencies
app/guidelines/Guidelines.md        # Development guide
```

### For Documentation Updates
```
README.md                           # User documentation
.github/instructions/               # AI guidance
.cursor/rules/                      # Automation rules
```

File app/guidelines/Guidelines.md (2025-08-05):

**Add your own guidelines here**
<!--

System Guidelines

# General guidelines

* Only use absolute positioning when necessary. Opt for responsive and well structured layouts that use flexbox and grid by default
* Refactor code as you go to keep code clean
* Keep file sizes small and put helper functions and components in their own files.

--------------

# Design system guidelines

* Use a base font-size of 14px
* Date formats should always be in the format “Jun 10”, with the addition of years only when necessary "June 10, 2025"
* The bottom toolbar should only ever have a maximum of 4 items
* Never use the floating action button with the bottom toolbar
* Chips should always come in sets of 3 or more
* Don't use a dropdown if there are 2 or fewer options

You can also create sub sections and add more specific details
For example:

## Button
The Button component is a fundamental interactive element in our design system, designed to trigger actions or navigate
users through the application. It provides visual feedback and clear affordances to enhance user experience.

### Usage
Buttons should be used for important actions that users need to take, such as form submissions, confirming choices,
or initiating processes. They communicate interactivity and should have clear, action-oriented labels.

### Variants
* Primary Button
  * Purpose : Used for the main action in a section or page
  * Visual Style : Bold, filled with the primary brand color
  * Usage : One primary button per section to guide users toward the most important action
* Secondary Button
  * Purpose : Used for alternative or supporting actions
  * Visual Style : Outlined with the primary color, transparent background
  * Usage : Can appear alongside a primary button for less important actions
* Tertiary Button
  * Purpose : Used for the least important actions
  * Visual Style : Text-only with no border, using primary color
  * Usage : For actions that should be available but not emphasized
-->

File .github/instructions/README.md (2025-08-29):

# Microplastic Detector AI Instructions

This directory contains modular AI instruction files for the microplastic detector project. Each file focuses on a specific aspect of the project to help AI agents work effectively with the codebase.

## Instruction Files

```
.github/instructions/
├── README.md                           # This file
├── architecture-overview.md           # Big picture architecture and workflow
├── api-contracts.md                   # Critical API contracts that must not be broken
├── development-workflows.md           # Development commands and testing procedures
├── coding-conventions.md              # Code style and organizational patterns
├── environment-setup.md               # Platform-specific setup and dependencies
├── frontend-guidelines.md             # React/Vite app specific guidance
├── documentation-sync.md              # Documentation maintenance procedures
└── file-pointers.md                   # Quick reference to key files and directories
```

## How to Use These Instructions

Each file is designed to be:
- **Focused**: Covers one specific aspect of the project
- **Self-contained**: Can be understood independently
- **Actionable**: Provides concrete guidance for AI agents
- **Maintainable**: Easy to update when the project evolves

## Integration

These instructions work together with:
- `.cursor/rules/` - Automated documentation maintenance rules
- `README.md` - User-facing project documentation
- Project structure and conventions

## Maintenance

When updating the project:
1. Update relevant instruction files
2. Check cross-references between files
3. Ensure consistency with main README.md
4. Update this overview if the file structure changes

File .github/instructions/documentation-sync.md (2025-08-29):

---
description: Documentation maintenance procedures and synchronization requirements
applyTo: "**"
---

# Documentation Synchronization

Purpose: Ensure documentation stays accurate and synchronized when the codebase changes.

## Files to Keep Synchronized

### Primary Documentation
- **`README.md`**: User-facing documentation with API signatures, setup instructions, and examples
- **`.github/instructions/`**: AI guidance files with contracts, workflows, and technical details
- **`.cursor/rules/`**: Automated documentation maintenance rules and triggers

### Secondary Documentation
- **`app/guidelines/Guidelines.md`**: Frontend-specific development guidelines
- **`protocols/microplastics-detection-protocol.md`**: Scientific methodology documentation
- **Inline code comments**: Function documentation and algorithm explanations

## Critical Update Triggers

### 🔴 High Priority (Update Immediately)
**Function signature changes** in core modules:
- `software/analyze_microplastics.py`
- `software/capture_image.py`
- `software/main.py`

**Actions Required:**
1. Update README code examples
2. Update API contracts in `.github/instructions/api-contracts.md`
3. Update development workflows if command usage changes
4. Verify test documentation matches new signatures

### 🟡 Medium Priority (Update Within Sprint)
**New dependencies** in:
- `software/requirements.txt`
- `app/package.json`

**Actions Required:**
1. Update setup instructions in README
2. Update environment setup documentation
3. Check platform-specific installation notes

**New features or modules:**
**Actions Required:**
1. Document in README usage section
2. Update AI workflows in `.github/instructions/`
3. Add to architecture overview if significant

### 🟢 Low Priority (Update When Convenient)
**Directory structure changes:**
**Actions Required:**
1. Update README structure listing
2. Update file pointers in AI instructions
3. Update .cursor/rules file patterns

**Test structure changes:**
**Actions Required:**
1. Update testing documentation in README
2. Update development workflows
3. Verify test file references in AI instructions

## Synchronization Checklist

### For API Changes
- [ ] Update function signature in README examples
- [ ] Update parameter tables and descriptions
- [ ] Update return value documentation
- [ ] Update API contracts section in AI instructions
- [ ] Update error handling documentation
- [ ] Verify validation rules are documented
- [ ] Update test documentation if test patterns change

### For New Dependencies
- [ ] Update installation instructions in README
- [ ] Update requirements sections
- [ ] Add platform-specific notes if needed
- [ ] Update environment setup documentation
- [ ] Check for conflicts with existing dependencies
- [ ] Update Docker/container configurations if applicable

### For Workflow Changes
- [ ] Update development command examples
- [ ] Update testing procedures
- [ ] Update AI development workflows section
- [ ] Verify script examples still work
- [ ] Update troubleshooting guides

### For File Structure Changes
- [ ] Update directory tree in README
- [ ] Update file pointers in AI instructions
- [ ] Update import examples
- [ ] Update .cursor/rules patterns
- [ ] Check relative path references

## Documentation Standards

### Code Examples
- Always use current, working examples
- Include expected output when helpful
- Show error cases and handling
- Use consistent formatting and style

### Cross-References
- Link between related documentation sections
- Maintain consistent terminology
- Update all references when renaming components
- Verify links are not broken

### Version Compatibility
- Note Python version requirements
- Document platform-specific differences
- Update compatibility matrices
- Test instructions on supported platforms

## Automation

### .cursor/rules Integration
The `.cursor/rules/` directory contains automated triggers for:
- API signature changes
- Dependency updates
- File structure modifications
- Documentation consistency checks

### Validation Scripts
Consider implementing:
```bash
# Check documentation consistency
./scripts/validate-docs.sh

# Test all code examples in documentation
./scripts/test-examples.sh

# Verify cross-references
./scripts/check-links.sh
```

## Review Process

### Before Committing
1. Review all documentation affected by code changes
2. Test code examples in documentation
3. Verify cross-references are accurate
4. Check for outdated screenshots or diagrams

### Pull Request Checklist
- [ ] Documentation updated for code changes
- [ ] Examples tested and working
- [ ] Cross-references verified
- [ ] Terminology consistent across files
- [ ] No broken links or references

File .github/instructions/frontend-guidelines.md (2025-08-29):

---
description: React/Vite frontend specific development guidance
applyTo: "app/**"
---

# Frontend Guidelines

Purpose: Development guidance for the React + Vite frontend application.

## Technology Stack

**Framework:** React with TypeScript
**Build Tool:** Vite
**Styling:** Tailwind CSS
**Package Manager:** npm

## Current Status

⚠️ **Important**: The frontend is currently **standalone** and **not connected** to the Python backend.

### What Works
- Independent React application
- Modern development experience with Vite
- Tailwind CSS for styling
- TypeScript for type safety

### What's Missing
- Backend API integration
- Real-time data from Python pipeline
- Image upload/analysis workflow
- Hardware status monitoring

## Development Commands

### Setup
```bash
cd app/
npm install
```

### Development Server
```bash
npm run dev
```
- Hot module replacement enabled
- Typically serves on `http://localhost:5173`
- Auto-reloads on file changes

### Production Build
```bash
npm run build
```
- Creates optimized bundle in `dist/`
- Ready for static hosting

### Preview Production Build
```bash
npm run preview
```
- Serves the production build locally
- Useful for testing build output

## Project Structure

```
app/
├── index.html                 # Entry HTML file
├── package.json              # Dependencies and scripts
├── vite.config.ts            # Vite configuration
├── tailwind.config.js        # Tailwind CSS config
├── postcss.config.mjs        # PostCSS configuration
├── styles.css                # Global styles
├── src/
│   ├── main.tsx              # Application entry point
│   ├── App.tsx               # Root component
│   └── components/           # React components
└── guidelines/
    └── Guidelines.md         # Component development guidelines
```

## Development Guidelines

### Component Architecture
- Follow functional component patterns
- Use TypeScript for all components
- Implement proper prop types and interfaces
- Keep components focused and reusable

### Styling Approach
- Use Tailwind CSS utility classes
- Avoid custom CSS when Tailwind classes suffice
- Follow responsive design principles
- Maintain consistent spacing and typography

### File Organization
- Group related components in subdirectories
- Use descriptive component and file names
- Export components from index files for clean imports
- Keep component files focused and manageable

## Future Integration Plans

### Backend Connection
When ready to connect to Python backend:

1. **API Endpoints**: Define REST API for Python services
2. **Real-time Updates**: Consider WebSocket for live analysis results
3. **File Upload**: Implement image upload for analysis
4. **Status Monitoring**: Show hardware and analysis status

### Recommended Architecture
```
Frontend (React) ←→ API Server ←→ Python Pipeline
                               ↓
                         Hardware (Pi + Camera)
```

## Development Best Practices

### Code Quality
- Use TypeScript strict mode
- Implement proper error boundaries
- Handle loading and error states
- Write unit tests for complex components

### Performance
- Implement code splitting for larger applications
- Optimize images and assets
- Use React.memo for expensive components
- Minimize bundle size

### Accessibility
- Use semantic HTML elements
- Implement proper ARIA attributes
- Ensure keyboard navigation
- Test with screen readers

## Deployment Options

### Static Hosting
Since the app is currently standalone:
- Netlify, Vercel, GitHub Pages
- AWS S3 + CloudFront
- Any static file server

### Future Full-Stack Deployment
When backend is integrated:
- Docker containers for Python + React
- Raspberry Pi with nginx reverse proxy
- Cloud hosting with API gateway

## Configuration

### Vite Configuration (`vite.config.ts`)
- TypeScript support configured
- Development server settings
- Build optimization options

### Tailwind Configuration (`tailwind.config.js`)
- Custom theme extensions
- Purge settings for production
- Plugin configurations

### Environment Variables
For future backend integration:
```bash
# .env.local
VITE_API_BASE_URL=http://localhost:8000
VITE_WS_URL=ws://localhost:8000/ws
```

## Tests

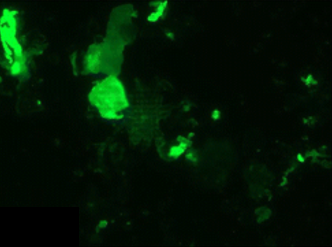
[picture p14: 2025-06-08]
tests/test-images/test_image_4.jpg

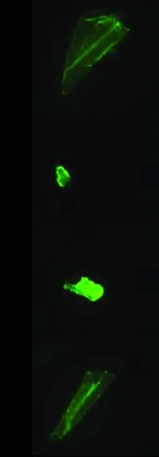
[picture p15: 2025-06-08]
tests/test-images/test_image_9.jpg

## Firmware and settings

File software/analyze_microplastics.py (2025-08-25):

import argparse
import cv2
import numpy as np
import matplotlib.pyplot as plt
import os

def analyze_microplastics(image_path, min_area=10, max_area=5000, low_thresh=10, high_thresh=30, show_image_processing=False):
    """
    Analyze a fluorescence image for microplastic particles.

    Args:
        image_path (str): Path to the captured image file.
        min_area (int): Minimum contour area to count (in pixels).
        max_area (int): Maximum contour area to count.
        low_thresh (int): Max count for 'Low' classification.
        high_thresh (int): Max count for 'Medium' classification.
        show_image_processing (bool): Whether to display the visualization plot.

    Returns:
        particle_count (int): Number of detected particles.
        category (str): 'Low', 'Medium', or 'High'

    Raises:
        ValueError: If min_area > max_area or if thresholds are invalid
        FileNotFoundError: If the image file doesn't exist
    """
    # Input validation
    if min_area > max_area:
        raise ValueError("min_area cannot be greater than max_area")
    
    # Ensure non-negative areas
    min_area = max(0, min_area)
    max_area = max(0, max_area)
    
    # Ensure thresholds are non-negative and properly ordered
    low_thresh = max(0, low_thresh)
    high_thresh = max(low_thresh, high_thresh)

    # Check if file exists
    if not os.path.exists(image_path):
        raise FileNotFoundError(f"Image file not found: {image_path}")

    # Load image
    image = cv2.imread(image_path)
    if image is None:
        raise ValueError(f"Failed to load image: {image_path}")

    print("Processing image for microplastics...")

    # Convert to HSV (Hue, Saturation, Value) color space
    # It separates color information (hue) from intensity (value), making it easier to isolate specific colors.
    # This allows us to create masks based on specific color ranges.
    hsv = cv2.cvtColor(image, cv2.COLOR_BGR2HSV)

    ''' Define solvatochromic hue ranges '''
    # These ranges are based on the expected fluorescence emission of solvatochromic dyes like Nile Red.
    # The ranges are defined in HSV color space of (lower_bound, upper_bound), where:
    #   H: Hue of 0-179 (color type)
    #   S: Saturation of 0-255 (color intensity)
    #   V: Value of 0-255 (brightness)
    # 50 is a common threshold for Saturation and Value to ensure we are detecting bright colors.
    # Values in experiment:
    #   Excitation source: LED GREEN DIFFUSED 3MM ROUND T/H with peak @ 515 nm
    #   Emission filter Lee No. 105 Orange: 560 nm long-pass filter
    #   Nile Red:       Ex: 510-550 nm; Em: 580-650 nm
    #       Datasheet:  Ex: 515 nm;     Em: 585 nm
    #       🇯🇵 study:   Ex: 450–490 nm; Em: 515–565 nm
    #   Hydrophobic (non-polar) plastics, e.g. polyethylene (PE) & polypropylene (PP):  Em: 580-630 nm
    #   Hydrophilic (polar) plastics, e.g. polystyrene (PS):                            Em: 631+ nm
    color_ranges = {
        "deep_red": [(340, 50, 50), (359, 255, 255)],   # (700, 661) nm
        "red":      [(0, 50, 50), (22, 255, 255)],      # (660, 626) nm
        "orange":   [(23, 50, 50), (51, 255, 255)],     # (625, 591) nm
        "yellow":   [(52, 50, 50), (70, 255, 255)],     # (590, 566) nm
        # "green":    [(71, 50, 50), (153, 255, 255)]      # (565, 500) nm
        # "blue":     [(154, 50, 50), (179, 255, 255)]     # (500, 450) nm
    }

    # Create masks for each color range
    # cv2.inRange(src, lowerb, upperb) creates a binary mask where pixels within the specified range are set to 255 (white),
    # and pixels outside the range are set to 0 (black).
    # The masks are combined to create a full mask that highlights all the relevant colors.
    full_mask = np.zeros_like(hsv[:, :, 0])
    masks = {}

    # Iterate through each color range and create a mask
    for name, (lower, upper) in color_ranges.items():
        # Convert lower and upper bounds to numpy arrays for cv2.inRange
        lower = np.array(lower)
        upper = np.array(upper)
        mask = cv2.inRange(hsv, lower, upper)
        masks[name] = mask
        full_mask = cv2.bitwise_or(full_mask, mask)
    
    # Deep red + red masks
    red_deep_red_mask = cv2.bitwise_or(masks["deep_red"], masks["red"])

    # Orange mask
    yellow_orange_mask = cv2.bitwise_or(masks["orange"], masks["yellow"])

    ''' Blur to reduce noise '''
    # Fluorescence images often have speckle noise or small bright pixels not related to microplastics.
    # Blurring helps smooth out these high-frequency artifacts before thresholding.
    # Sharp edges or pixel spikes can confuse the thresholding process.
    # Threshold algorithms (like Otsu’s method) work better when the image is smoothed.
    # It helps ensure that true signals (plastics) stand out from background variations.
    # cv2.GaussianBlur(src, ksize, sigmaX) applies a Gaussian blur to the image.
    #   src: source image
    #   ksize: size of the Gaussian kernel
    #       An odd integer tuple, e.g., (5, 5).
    #       Determines the extent of blurring; larger values result in more blur.
    #       A kernel size of (5, 5) is a common choice for moderate blurring.
    #   sigmaX: standard deviation in the X direction (0 means it is calculated based on ksize)
    blurred = cv2.GaussianBlur(full_mask, (3, 3), 0)

    ''' Bilateral filter to preserve edges '''
    # The bilateral filter smooths the image while preserving edges, making it useful for fluorescence images.
    # cv2.bilateralFilter(src, d, sigmaColor, sigmaSpace) applies a bilateral filter to the image.
    #   src: source image
    #   d: diameter of the pixel neighborhood used during filtering (must be odd)
    #   sigmaColor: filter sigma in color space (larger values mean more colors will be mixed)
    #   sigmaSpace: filter sigma in coordinate space (larger values mean farther pixels will influence each other)
    bilateral_filtered = cv2.bilateralFilter(full_mask, d=3, sigmaColor=75, sigmaSpace=75)

    ''' Threshold (Otsu’s method) '''
    # Otsu's method automatically determines a threshold value to separate foreground from background.
    # It is particularly useful for images with bimodal histograms, like fluorescence images.
    # cv2.threshold(src, thresh_value, max_value, method)
    # thresh_value: initial threshold — set to 0 to enable Otsu’s auto-calculation
    # method
    #   THRESH_BINARY: pixels > threshold → 255 (white); others → 0 (black)
    #   THRESH_OTSU: automatically calculates the optimal threshold to separate foreground from background based on image histogram
    _, binary = cv2.threshold(blurred, 0, 255, cv2.THRESH_BINARY + cv2.THRESH_OTSU)

    ''' Morphological cleanup '''
    # Morphological operations help remove small noise and enhance the structure of detected particles.
    # cv2.getStructuringElement(shape, ksize) creates a structuring element for morphological operations.
    #   shape: cv2.MORPH_ELLIPSE, which creates an elliptical structuring element, which is effective for circular particles.
    #   ksize: size of the structuring element (3x3 in this case)
    # cv2.morphologyEx(src, op, kernel) applies a morphological operation to the image.
    #   src: source image (binary mask)
    #   op: morphological operation to apply
    #       cv2.MORPH_OPEN: removes small objects from the foreground (noise) while preserving larger structures.
    #   kernel: structuring element created above
    kernel = cv2.getStructuringElement(cv2.MORPH_ELLIPSE, (3, 3))
    cleaned = cv2.morphologyEx(binary, cv2.MORPH_OPEN, kernel)

    ''' Find contours '''
    # cv2.findContours(image, mode, method) detects contours in a binary image.
    #   mode: cv2.RETR_EXTERNAL retrieves only the outer contours (useful for counting particles)
    #   method: cv2.CHAIN_APPROX_SIMPLE compresses horizontal, vertical, and diagonal segments and leaves only their endpoints.
    #       This reduces memory usage and speeds up contour processing.
    # The contours are stored in a list, where each contour is represented as an array of points.
    # The second return value is the hierarchy of contours, which we don't need here.
    contours, _ = cv2.findContours(cleaned, cv2.RETR_EXTERNAL, cv2.CHAIN_APPROX_SIMPLE)

    # Count valid particles
    count = 0
    for shape in contours:
        area = cv2.contourArea(shape)
        if min_area < area < max_area:
            count += 1

    category = "Low" if count < low_thresh else "Medium" if count < high_thresh else "High"


    ''' Visualize only if show_image_processing is True '''
    if show_image_processing:
        ''' Draw contours on the cleaned image '''
        # This step visualizes the detected contours on the cleaned image.
        # cv2.drawContours(image, contours, contourIdx, color, thickness)
        #   image: the image on which to draw the contours
        #   contours: list of contours to draw
        #   contourIdx: -1 means draw all contours; you can specify an index to draw a specific contour
        #   color: color of the contours (green in this case)
        #   thickness: thickness of the contour lines in pixels
        contour_img = image.copy()
        cv2.drawContours(contour_img, contours, -1, (0, 255, 0), 1)

        # Create a 2x4 grid of subplots
        fig, axes = plt.subplots(2, 4, figsize=(16, 10))
        axes[0, 0].imshow(cv2.cvtColor(image, cv2.COLOR_BGR2RGB))
        axes[0, 0].set_title("Original image")
        axes[0, 0].axis('off')

        axes[0, 1].imshow(red_deep_red_mask, cmap='gray')
        axes[0, 1].set_title("Red/deep red channels")
        axes[0, 1].axis('off')

        axes[0, 2].imshow(yellow_orange_mask, cmap='gray')
        axes[0, 2].set_title("Yellow/orange channels")
        axes[0, 2].axis('off')

        axes[0, 3].imshow(full_mask, cmap='gray')
        axes[0, 3].set_title("Combined mask")
        axes[0, 3].axis('off')

        axes[1, 0].imshow(blurred, cmap='gray')
        axes[1, 0].set_title("Blurred image")
        axes[1, 0].axis('off')

        axes[1, 1].imshow(bilateral_filtered, cmap='gray')
        axes[1, 1].set_title("Bilateral filter")
        axes[1, 1].axis('off')

        axes[1, 2].imshow(cleaned, cmap='gray')
        axes[1, 2].set_title("Cleaned image")
        axes[1, 2].axis('off')

        axes[1, 3].imshow(cv2.cvtColor(contour_img, cv2.COLOR_BGR2RGB))
        axes[1, 3].set_title("Contours detected")
        axes[1, 3].axis('off')

        plt.suptitle(f"Detected particles: {count} → Category: {category}", fontsize=14)
        plt.tight_layout()
        plt.show()

    return count, category

if __name__ == "__main__":
    parser = argparse.ArgumentParser(description="Analyze a captured image for microplastics")
    parser.add_argument(
        "--show_image_processing",
        action="store_true",
        help="Show image processing steps in a plot"
    )
    parser.add_argument(
        "--image_path",
        type=str,
        default="./tests/test-images/test_image_1.jpg",
        help="Path to the input image"
    )
    args = parser.parse_args()

    count, level = analyze_microplastics(args.image_path, show_image_processing=args.show_image_processing)
    print(f"Detected particles: {count} → Category: {level}")

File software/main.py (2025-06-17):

from software.illuminate_sample import illuminate_sample, cleanup
from software.capture_image import capture_image
from software.analyze_microplastics import analyze_microplastics

def run_capture_and_analysis():
    try:
        illuminate_sample()
        # Capture image with lights on
        path = capture_image()
        count, level = analyze_microplastics(path)
        print(f"Detected particles: {count} → Category: {level}")
    finally:
        # Ensure lights are turned off even if capture fails
        illuminate_sample(lights=False)
        cleanup()

if __name__ == "__main__":
    run_capture_and_analysis()

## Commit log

2025-06-17 Updated functions for capture and analyse which can be run on a Raspberry Pi
2025-07-28 Hardware updates
    [camera_extension.scad, camera_extension.stl, core_body.scad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]
2025-08-14 additional camera controls
2025-08-21 Add new leg models and update LED dispersion simulation
    - Introduced `core_leg_80.scad` and `core_leg_90.scad` for 80mm and 90mm leg designs with external threads.
    - Modified `led angels and dispersion of light onto membrane.scad` to adjust LED count and dimensions, and improved beam path visualization.
    - Updated microplastics detection protocol to reflect changes in materials and procedures, including sample volume and staining method.
    - Enhanced `analyze_microplastics.py` with improved color detection ranges, added bilateral filtering, and updated visualization of results.
    [core_body.scad, core_body_151031VS06000.scad, core_body_WP710A10ZGDK.scad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]
2025-08-23 Remove outdated LED excitation source
2025-08-25 Add core leg models with varying heights and thread specifications
    - Introduced core_leg_64.scad with a leg height of 64mm and standard metric thread pitches.
    - Introduced core_leg_66.scad with a leg height of 66mm and the same thread specifications.
    - Both models utilize a screw thread generation function for accurate threading.
    - Implemented a closed polyhedron generation method for the legs.
    [core_body_WP710A10ZGDK.stl, core_cover.stl, core_cover_v2.scad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]
2025-08-29 Refactor code structure for improved readability and maintainability
    [core_body_WP710A10ZGDK.scad, core_body_WP710A10ZGDK.stl, core_body_WP710A10ZGDK_10.stl]
